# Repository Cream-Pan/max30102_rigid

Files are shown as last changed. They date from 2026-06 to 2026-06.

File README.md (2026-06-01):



# MAX30102_rigid

MAX30102を用いた小型PPGセンサ用リジッド基板である．
耳装着型デバイスやウェアラブルデバイスへの組み込みを想定し，光電脈波（PPG）を取得するために設計した．

## 使用技術一覧

<p style="display: inline">
  
  
  
  
</p>

## 目次

1. [概要](#概要)
2. [基板仕様](#基板仕様)
3. [回路構成](#回路構成)
4. [ディレクトリ構成](#ディレクトリ構成)
5. [Git管理方針](#git管理方針)
6. [製造データ](#製造データ)
7. [設計上の注意](#設計上の注意)

## 概要

本リポジトリは，MAX30102を搭載したリジッド基板のKiCadプロジェクトを管理するためのものである．
MAX30102は，赤色LED，赤外LED，フォトダイオード，ADCを内蔵した光学式センサであり，PPG波形の取得や心拍推定に利用できる．

本基板では，MAX30102を小型基板上に実装し，外部マイコンからI2C経由でPPGデータを取得する構成としている．

<p align="right">(<a href="#top">トップへ</a>)</p>

---

## 基板仕様

| 項目 | 内容 |
| --- | --- |
| 基板名 | MAX30102_rigid |
| センサ | MAX30102 |
| 通信方式 | I2C |
| I2Cアドレス | 0x57 |
| 取得データ | Red / IR PPG |
| 用途 | PPG取得，心拍推定，ウェアラブルセンシング |
| 設計ツール | KiCad |

<p align="right">(<a href="#top">トップへ</a>)</p>

---

## 回路構成

本基板は，MAX30102と外部マイコンをI2Cで接続する構成である．

```text
MCU
├── SDA
├── SCL
└── INT

MAX30102
├── Red LED
├── IR LED
├── Photodiode
├── ADC
└── FIFO
```

MAX30102内部のFIFOに格納されたPPGデータをマイコン側で読み出し，心拍推定や波形解析に利用する．

<p align="right">(<a href="#top">トップへ</a>)</p>

---

## ディレクトリ構成

```text
.
├── .gitignore
├── .history/                         # VSCode等の履歴フォルダ，Git管理対象外
├── garbar/                           # Gerber出力用フォルダ
├── jlcpcb/                           # JLCPCB発注用データ
├── MAX30102_rigid-backups/           # KiCadバックアップ，Git管理対象外
├── fp-info-cache                     # KiCadキャッシュ，Git管理対象外
├── MAX30102_rigid.kicad_pcb          # PCBレイアウト
├── MAX30102_rigid.kicad_prl          # KiCadローカル設定，Git管理対象外
├── MAX30102_rigid.kicad_pro          # KiCadプロジェクト
├── MAX30102_rigid.kicad_sch          # 回路図
└── MAX30102_test1.kicad_prl          # KiCadローカル設定，Git管理対象外
```

基本的に，Gitで管理する主要ファイルは以下である．

```text
MAX30102_rigid.kicad_pro
MAX30102_rigid.kicad_sch
MAX30102_rigid.kicad_pcb
.gitignore
README.md
```

<p align="right">(<a href="#top">トップへ</a>)</p>

---

## Git管理方針

本リポジトリでは，KiCadプロジェクト本体をGitで管理し，自動生成ファイルや個人環境依存ファイルは管理対象外とする．

主に以下をGit管理対象外とする．

```text
*.kicad_prl
fp-info-cache
*-backups/
*_backups/
*.bak
*-bak
_autosave-*
*.lck
.history/
```

また，製造出力ファイルも基本的には自動生成物として扱う．

```text
*.gbr
*.drl
*.pos
*.rpt
*.zip
```

本プロジェクトでは，自作シンボルおよび自作フットプリントを `kicad_my_library` リポジトリで管理している．  
KiCadで本プロジェクトを開く前に，`kicad_my_library` をcloneし，KiCadのライブラリ設定に登録する必要がある．

```powershell
git clone https://github.com/Cream-Pan/kicad_my_library.git
```

登録するライブラリは以下である．

```text
Footprint Library:
kicad_my_library/footprints/MyLibrary.pretty

Symbol Library:
kicad_my_library/symbols/MyLibrary.kicad_sym
```

KiCad上でのライブラリNicknameは以下に統一する．
```text
MyLibrary
```

Nicknameを変更すると，MyLibrary:C0603 のような既存の参照が壊れる可能性がある．

発注時点の製造データを残す場合は，必要に応じてGitHub Releasesや別フォルダで管理する．

<p align="right">(<a href="#top">トップへ</a>)</p>

---

## 製造データ

`jlcpcb` フォルダには，JLCPCBでの基板製造および部品実装を想定したデータを配置する．

主な出力対象は以下である．

* Gerber
* Drill
* BOM
* CPL

現状の `.gitignore` では，`.gbr`，`.drl`，`.zip` などの製造出力はGit管理対象外としている．
そのため，発注データをGitHub上に残したい場合は，`.gitignore` の例外設定またはGitHub Releasesでの管理を検討する．

<p align="right">(<a href="#top">トップへ</a>)</p>

---

## 設計上の注意

### 1．電源

MAX30102では，LED駆動時にパルス的な電流が流れるため，電源ラインの安定性が重要である．
VLEDおよびVDD近傍にデカップリングコンデンサを配置し，電源ノイズがPPG信号に混入しにくい構成とする．

### 2．光学設計

PPG信号は，センサと皮膚の距離，接触状態，外光の混入に影響される．
そのため，実装時には以下に注意する．

* センサと皮膚の距離を一定に保つ
* 外光を遮断する
* 光学窓上にフラックス残渣や汚れを残さない
* 皮膚との接触圧が過度に変動しない構造にする

### 3．I2C通信

MAX30102はI2Cで通信するため，SDAおよびSCLのプルアップ抵抗，配線長，ノイズ混入に注意する．
複数センサと同一バス上で使用する場合は，I2Cアドレスの重複やバス容量にも注意する．

<p align="right">(<a href="#top">トップへ</a>)</p>

---

開発者情報
Name: Takato Ishii

Portfolio: https://takato-ishii.vercel.app/

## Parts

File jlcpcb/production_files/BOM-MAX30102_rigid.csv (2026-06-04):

Comment | Designator | Footprint | LCSC | Quantity
0.1μ | C4,C6,C7,C8 | C_0402_1005Metric | C77020 | 4
10μ | C5 | C0603 | C2959727 | 1
4.7k | R1,R2,R3,R4,R5,R6 | R_0402_1005Metric | C281778 | 6
4.7μ | C1,C2,C3 | C0603 | C389010 | 3
MAX30102 | U1 | Maxim_OLGA-14_3.3x5.6mm_P0.8mm | C6454833 | 1
~ | U3 | MICROPARK_L1.6-W1.6-P0.50-BL-1 | C107408 | 1
~ | FPC1 | FPC-SMD_AFC07-S05FCC-00 | C262199 | 1
~ | U2 | SOT-23-5_L2.9-W1.6-P0.95-LS2.8-BL | C3748843 | 1

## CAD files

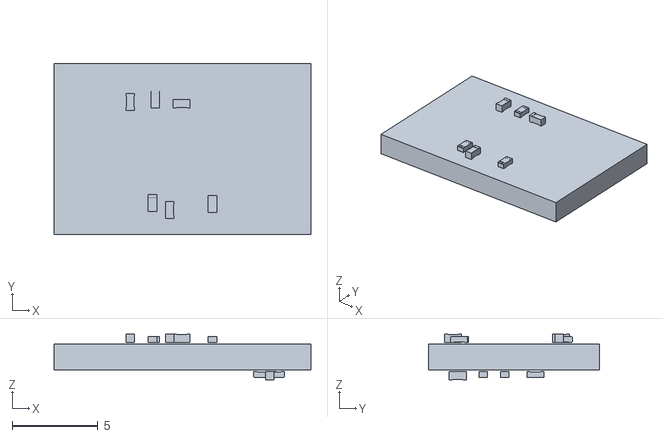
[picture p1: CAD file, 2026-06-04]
.stl
15.0 x 10.0 x 2.68

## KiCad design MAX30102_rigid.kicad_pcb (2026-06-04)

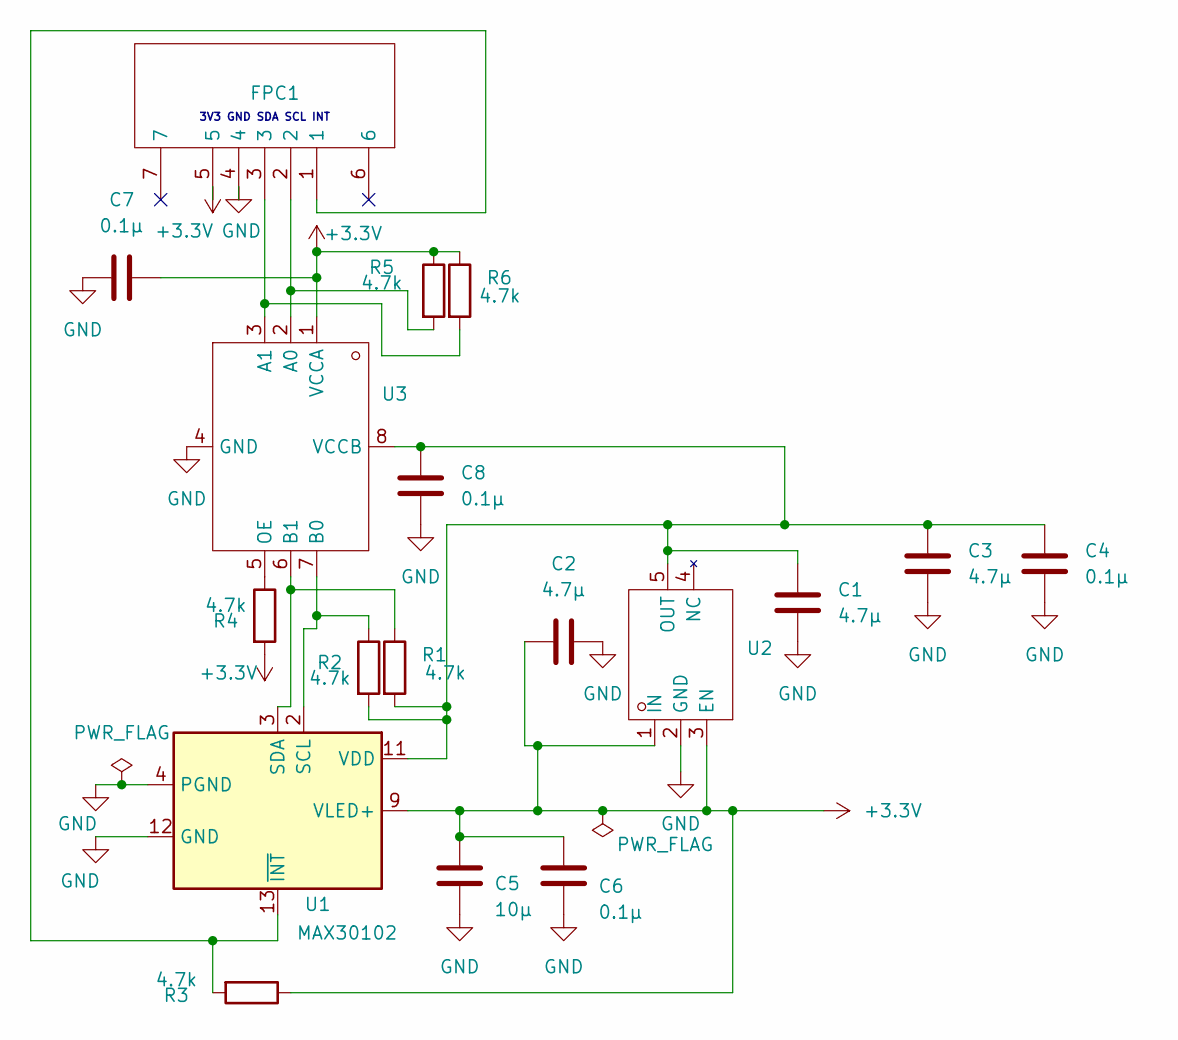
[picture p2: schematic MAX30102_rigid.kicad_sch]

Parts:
C1, C2, C3: 4.7μ; C0603
C4, C6, C7, C8: 0.1μ; C_0402_1005Metric
C5: 10μ; C0603
FPC1: FPC-SMD_AFC07-S05FCC-00; Manufacturer Part AFC07-S05FCC-00; LCSC Part Name 间距:0.5mm P数:5P 抽屉式 下接
R1, R2, R3, R4, R5, R6: 4.7k; R_0402_1005Metric
U1: MAX30102; Maxim_OLGA-14_3.3x5.6mm_P0.8mm
U2: SOT-23-5_L2.9-W1.6-P0.95-LS2.8-BL; Manufacturer Part TPS7A0218PDBVR; LCSC Part Name 具有使能功能的 200mA、毫微功耗 IQ (25nA)、低压降 (LDO) 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
U3: MICROPARK_L1.6-W1.6-P0.50-BL-1; Manufacturer Part FXMA2102L8X; LCSC Part Name 双电源 2位电压转换器/缓冲器/中继器/隔离器 用于I2C应用

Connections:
+3.3V: C2.1, C5.1, C6.1, C7.1, FPC1.5, R3.1, R4.2, R5.1, R6.1, U1.9 (VLED+), U1.10 (VLED+), U2.1 (IN), U2.3 (EN), U3.1 (VCCA)
GND: C1.2, C2.2, C3.2, C4.2, C5.2, C6.2, C7.2, C8.2, FPC1.4, U1.4 (PGND), U1.12 (GND), U2.2 (GND), U3.4 (GND)
unnamed: R2.1, U1.2 (SCL), U3.7 (B0)
unnamed: R1.1, U1.3 (SDA), U3.6 (B1)
unnamed: C1.1, C3.1, C4.1, C8.1, R1.2, R2.2, U1.11 (VDD), U2.5 (OUT), U3.8 (VCCB)
unnamed: FPC1.1, R3.2, U1.13 (~INT)
unnamed: FPC1.2, R5.2, U3.2 (A0)
unnamed: FPC1.3, R6.2, U3.3 (A1)
unnamed: R4.1, U3.5 (OE)

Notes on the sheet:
3V3 GND SDA SCL INT

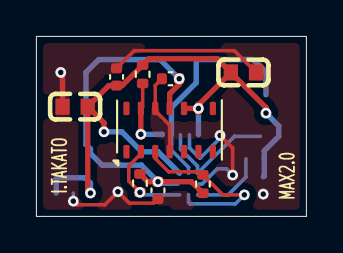
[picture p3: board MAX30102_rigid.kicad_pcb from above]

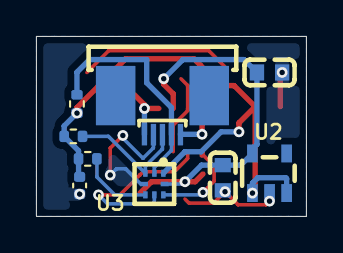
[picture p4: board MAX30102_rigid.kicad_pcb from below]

Board: 2 copper layers, 15.0 x 10.0 mm, 18 parts (9 on the bottom side), 9 nets.

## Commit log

2026-06-01 Initial KiCad project
    [BOM-MAX30102_test1.csv, MAX30102_rigid.kicad_pcb, MAX30102_rigid.kicad_sch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]
2026-06-02 Update for Ver2.0
    [MAX30102_rigid.kicad_pcb, MAX30102_rigid.kicad_sch]
2026-06-04 Update for Order
    [.stl, BOM-MAX30102_rigid.csv, BOM-MAX30102_test1.csv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]
